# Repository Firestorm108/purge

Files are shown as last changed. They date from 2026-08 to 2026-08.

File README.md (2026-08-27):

# purge
**Purge** is a fully open source wireless inductively coupled plasma cleaner consisting of three isolated PCBs; the external user-control board, STM32 based motherboard, spark generator/ICP driver, and a vaccum chamber.

# PCB & Assembly
Screenshot 2026-08-26 at 1 35 50 PM
Screenshot 2026-08-26 at 3 20 42 PM

Screenshot 2026-08-26 at 2 14 10 PM
Screenshot 2026-08-26 at 3 26 43 PM

# The Process

**Purge** is a specialized type of plasma cleaner. There are **zero** electrodes in the vacuum chamber, meaning the sterility levels are very high, atomically sterile even. There are three stages to the process.

<h3>Stage 1: Chamber Prep</h3>
A 4.5 CFM standard vacuum pump evacuates much of the air inside of the glass dome to 37.5 mTorr. This makes the plasma much easier to form, as there is a reduced gas density. 
The chamber is made up of a custom machined aluminum base and a cheap glass dome you can find on Amazon. There is a slight implosion risk, so it is important you wear proper PPE.

<h3>Stage 2: Plasma Formation</h3>
There are two parts to the plasma formation. Since inductively coupled plasma (ICP) is relatively harder to form than capacitively coupled plasma or direct discharges, simply running the RF through the primary coil may not form the plasma.
To form the plasma, we initiate a short high voltage spark with an external device. In this case, I'm using a high frequency solid state plasma flame generator, similar to the ICP circuit itself. It ionizes some of the gas in the chamber, making
ICP form much easier. The ICP driver powers on after this, and the chamber fills with plasma.

<h3>Stage 3: Adjustment & Control</h3>
You can change the plasma inside the chamber using the built in STM32 interrupter. It allows you to pulse the plasma at any desired frequency within the chip and MOSFETs limits. This can be useful if you are trying to 
do research using the device, or wish to adjust power levels based on the item you are sterilizing.

# Bill of Materials

| Item | Price | Link |
|---|---:|---|
| Control PCB | $10 | JLCPCB |
| Header Pins | $3 | [AliExpress](https://www.aliexpress.us/item/3256801327743339.html) |
| OLED Screen | $4 | [AliExpress](https://www.aliexpress.us/item/3256805954920554.html) |
| 10K Potentiometers | $4 | [AliExpress](https://www.aliexpress.us/item/3256809938132755.html) |
| Push Button | $4 | [AliExpress](https://www.aliexpress.us/item/3256808590713102.html) |
| 3mm Flat Top LEDs | $2 | [AliExpress](https://www.aliexpress.us/item/2251801539552759.html) |
| F-F Jumpers | $2 | [AliExpress](https://www.aliexpress.us/item/2255800018543465.html) |
| ICP Driver PCB + Assembly | $55 | JLCPCB |
| FQA18N50 MOSFETs | $10 | [AliExpress](https://www.aliexpress.us/item/3256811881586105.html) |
| 6kV 33pF Capacitors | $2 | [AliExpress](https://www.aliexpress.us/item/2251832494176278.html) |
| 12AWG Solid Core | $4 | [AliExpress](https://www.aliexpress.us/item/3256808900976117.html) |
| Massive Heatsink | $10 | [AliExpress](https://www.aliexpress.us/item/3256809168389115.html) |
| HFSSTC Module | $24 | [AliExpress](https://www.aliexpress.us/item/3256810369157220.html) |
| 24AWG Solid Core (Inductor Wire) | $7 | [Amazon](https://www.amazon.com/0-2mm%C2%B2-Electrical-Colors-Tinned-breadboard/dp/B09WMQZYXV/) |
| 6AWG Primary Copper | $24 | [Amazon](https://www.amazon.com/99-9-Copper-Diameter-Jewelry-Making/dp/B0CNRT19WB/) |
| Purge Motherboard PCB + Assembly | $80 | JLCPCB |
| 24V → 12V Isolation SMPS | $6 | [AliExpress](https://www.aliexpress.us/item/3256807230654430.html) |
| 24V 10A Power Supply | $30 | [Amazon](https://www.amazon.com/Power-Supply-Adapter-Transformers-Universal/dp/B0D5B33JCH) |
| JLCPCB Customs & Shipping | $91 | JLCPCB |
| 4" × 7" Glass Dome | $30 | [Amazon](https://www.amazon.com/Plymor-Brand-Glass-Display-Cloche/dp/B006XIQGX8/) |
| 4.5 CFM Vacuum Pump | $60 | [Amazon](https://www.amazon.com/VECOTOOLS-Foldable-Automotive-Household-Maintenance/dp/B0GZVLP3PL/) |
| Hosing & Gauge | $28 | [Amazon](https://www.amazon.com/R410A-Recharge-Manifold-Gauge-Set/dp/B0DZ6G6ZBT/) |
| SAE to NPT Adapter | $9 | [Amazon](https://www.amazon.com/uxcell-Fitting-Connector-Conditioner-Refrigeration/dp/B08MZ4TPMZ/) |
| NPT Tap | $7 | [Amazon](https://www.amazon.com/Drill-America-DWTPT1-Qualtech-Carbon/dp/B01DZD1SSQ/) |
| M5 × 100mm Threaded Rods | $10 | [Amazon](https://www.amazon.com/LWCUSNJ-Threaded-M5-0-8mm-Stainless-Threads/dp/B0FHB8P689/) |
| Silicone Caulk | $3 | [Amazon](https://www.amazon.com/White-Acrylic-Latex-Caulk-Silicone/dp/B00GVLHBDG/) |
| Custom Aluminum Base Plate | $50 | JLC CNC |
| Silicone Isolation Feet | $20 | [Amazon](https://www.amazon.com/Isolation-Feet-8Pack-Turntable-Subwoofer-Resonance/dp/B0FX8S3D77) |

**Total: $589**

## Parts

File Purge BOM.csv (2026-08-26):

Item | Price | Link
Control PCB | $10 | JLCPCB
Header Pins | $3 | https://www.aliexpress.us/item/3256801327743339.html
OLED Screen | $4 | https://www.aliexpress.us/item/3256805954920554.html?
10K Potentiometers | $4 | https://www.aliexpress.us/item/3256809938132755.html
Push Button | $4 | https://www.aliexpress.us/item/3256808590713102.html?
3mm Flat Top LEDs | $2 | https://www.aliexpress.us/item/2251801539552759.html?
F-F Jumpers | $2 | https://www.aliexpress.us/item/2255800018543465.html
ICP Driver PCB + Assembly | $55 | JLCPCB
FQA18N50 MOSFETs | $10 | https://www.aliexpress.us/item/3256811881586105.html
6kV 33pF Capacitors | $2 | https://www.aliexpress.us/item/2251832494176278.html
12AWG Solid Core | $4 | https://www.aliexpress.us/item/3256808900976117.html
Massive Heatsink | $10 | https://www.aliexpress.us/item/3256809168389115.html
HFSSTC Module | $24 | https://www.aliexpress.us/item/3256810369157220.html?
24AWG Solid Core (Inductor Wire) | $7 | https://www.amazon.com/0-2mm%C2%B2-Electrical-Colors-Tinned-breadboard/dp/B09WMQZYXV/
6AWG Primary Copper | $24 | https://www.amazon.com/99-9-Copper-Diameter-Jewelry-Making/dp/B0CNRT19WB/
Purge Motherboard PCB + Assembly | $80 | JLCPCB
24V -> 12V Isolation SMPS | $6 | https://www.aliexpress.us/item/3256807230654430.html
24V 10A Power Supply | $30 | https://www.amazon.com/Power-Supply-Adapter-Transformers-Universal/dp/B0D5B33JCH
JLCPCB Customs & Shipping | $91 | :( JLCPCB
4"x7" Glass Dome | $30 | https://www.amazon.com/Plymor-Brand-Glass-Display-Cloche/dp/B006XIQGX8/ref=ast_sto_dp_puis?th=1
4.5CFM Vacuum Pump | $60 | https://www.amazon.com/VECOTOOLS-Foldable-Automotive-Household-Maintenance/dp/B0GZVLP3PL/
Hosing & Gauge | $28 | https://www.amazon.com/R410A-Recharge-Manifold-Gauge-Set/dp/B0DZ6G6ZBT/
SAE to NPT Adapter | $9 | https://www.amazon.com/uxcell-Fitting-Connector-Conditioner-Refrigeration/dp/B08MZ4TPMZ/
NPT Tap | $7 | https://www.amazon.com/Drill-America-DWTPT1-Qualtech-Carbon/dp/B01DZD1SSQ/
M5 x 100mm Threaded Rods | $10 | https://www.amazon.com/LWCUSNJ-Threaded-M5-0-8mm-Stainless-Threads/dp/B0FHB8P689/
Silicone Caulk | $3 | https://www.amazon.com/White-Acrylic-Latex-Caulk-Silicone/dp/B00GVLHBDG/
Custom Aluminum Base Plate | $50 | JLC CNC
Silicone Isolation Feet | $20 | https://www.amazon.com/Isolation-Feet-8Pack-Turntable-Subwoofer-Resonance/dp/B0FX8S3D77
Total: | $589

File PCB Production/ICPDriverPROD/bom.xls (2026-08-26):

Comment | Designator | Footprint | JLCPCB Part #
SIG | L1,J4,J1,J2,J5,L1,J4,J1,J2,J5,L1,J4,J1,J2,J5,L1,J4,J1,J2,J5,L1,J4,J1,J2,J5 | CONN-TH_P10.16_KF135T-10.16-2P | C475108
1K0.5W | R1,R2 | R_2512_6332Metric | C54315
1uF100V | C1 | C_1206_3216Metric | C13832
450V4.7nF | C2,C3 | C_1812_4532Metric | C692321
10K | R3,R4 | R_0603_1608Metric | C25804
IPT007N06N | U1,U2 | HSOF-8_IPT007N06N | C122552

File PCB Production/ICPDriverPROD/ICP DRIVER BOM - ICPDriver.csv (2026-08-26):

Id | Designator | Footprint | Quantity | Comment | Supplier and ref
1 | C1 | C_1206_3216Metric | 1 | 1uF 100V
2 | C2, C3 | C_1812_4532Metric | 2 | 450V 4.7nF
3 | C4, C5, C6, C7 | C_Disc_D7.5mm_W5.0mm_P7.50mm | 4 | 6kV 33pF
4 | J1 | CONN-TH_P10.16_KF135T-10.16-2P | 1 | ICP Primary
5 | J2 | CONN-TH_P10.16_KF135T-10.16-2P | 1 | Plasma Flame
6 | J4 | CONN-TH_P10.16_KF135T-10.16-2P | 1 | VIN
7 | J5 | CONN-TH_P10.16_KF135T-10.16-2P | 1 | SIG
8 | L1 | CONN-TH_P10.16_KF135T-10.16-2P | 1 | 10uH
9 | Q1 | TO-247-3_Vertical | 1 | FDA18N50
10 | R1, R2 | R_2512_6332Metric | 2 | 1K 0.5W
11 | R3, R4 | R_0603_1608Metric | 2 | 10K
12 | RV1 | RES-ADJ-TH_RK1631110U1Q | 1 | 10K
13 | U1, U2 | HSOF-8_IPT007N06N | 2 | IPT007N06N

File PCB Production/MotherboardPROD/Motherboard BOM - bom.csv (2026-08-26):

Id | Designator | Footprint | Quantity | Comment | Supplier and ref
1 | C10, C17, C33, C36, C37, C44, C45 | C_0603_1608Metric | 7 | 10uF
2 | C11, C14, C15, C30, C31, C39 | C_0603_1608Metric | 6 | 1uF
3 | C12, C13 | C_0603_1608Metric | 2 | 2.2uF
4 | C16, C18, C19, C24, C25, C26, C27, C28, C29, C38, C43 | C_0402_1005Metric | 11 | 100nF
5 | C20, C21 | C_0402_1005Metric | 2 | 10pF
6 | C22, C23 | C_0402_1005Metric | 2 | 30pF
7 | D1, D3 | D_SOD-323 | 2 | 1N5819WS
8 | D5, D6, D7, D8 | LED_0805_2012Metric | 4 | LED
9 | J1 | CONN-TH_P10.16_KF135T-10.16-2P | 1 | 12VDC
10 | J3 | USB_C_Receptacle_HRO_TYPE-C-31-M-12 | 1 | USB_C_Receptacle_USB2.0_14P
11 | J4 | PinHeader_1x12_P2.54mm_Vertical | 1 | Conn_01x12
12 | J9 | CONN-TH_P10.16_KF135T-10.16-2P | 1 | Driver Signals
13 | R3, R6, R7, R9, R10, R11, R12, R18, R22, R23, R24, R25 | R_0603_1608Metric | 12 | 10K
14 | R4, R5 | R_0603_1608Metric | 2 | 5.1K
15 | R13, R14, R15, R20 | R_0603_1608Metric | 4 | 4.7K
16 | R17, R19 | R_0603_1608Metric | 2 | 330
17 | SW1, SW2 | SW_Push_SPST_NO_Alps_SKRK | 2 | SW_Push
18 | U1 | LQFP-64_10x10mm_P0.5mm | 1 | STM32H573RIT6
19 | U3 | TO-263-2_L10.0-W9.2-P5.08-LS15.3-TL-CW | 1 | L7805ABD2T-TR
20 | U4 | SOT-23-6 | 1 | USBLC6-2SC6
21 | U5 | SOT-223-3_TabPin2 | 1 | LD1117S33TR_SOT223
22 | U6, U11 | SOIC-8_L5.0-W4.0-P1.27-LS6.0-BL | 2 | TC4420EOA713
23 | U8, U10 | OPTO-SMD-5_L3.7-W4.6-P1.27-LS7.0-BR | 2 | TLP2362
24 | X1 | CRYSTAL-SMD_L3.2-W1.5-1 | 1 | FC-135 32.7680KA-AG3
25 | X2 | OSC-SMD_L5.0-W3.2 | 1 | ABM3-8.000MHZ-D2Y-T

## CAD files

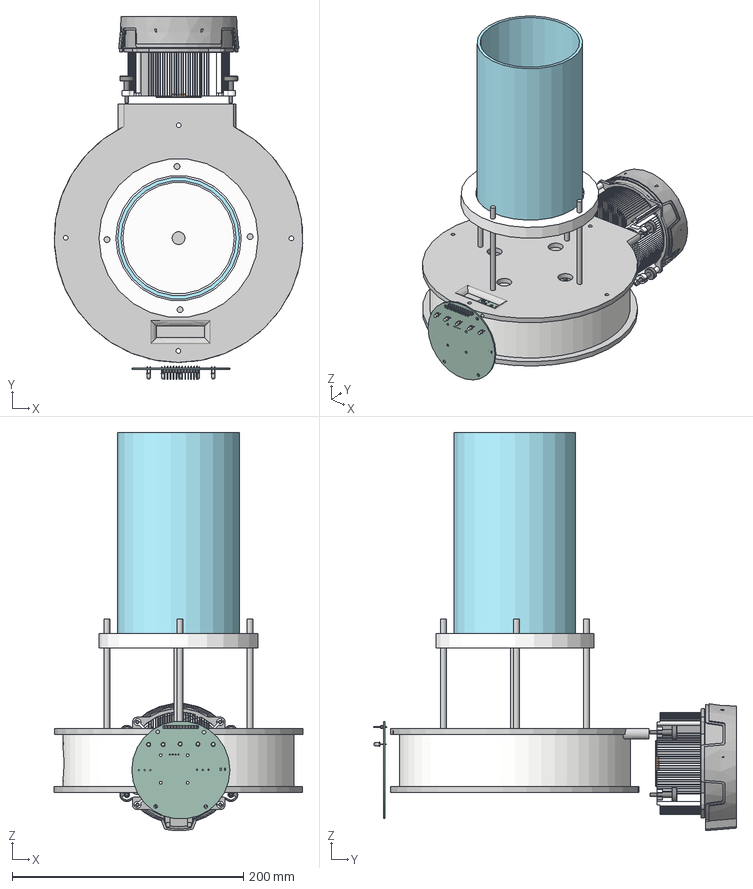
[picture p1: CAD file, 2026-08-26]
CAD/Assembly.step
214.9 x 313.9 x 344.5 mm

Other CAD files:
CAD/Assembly.f3z
CAD_/Assembly.f3z

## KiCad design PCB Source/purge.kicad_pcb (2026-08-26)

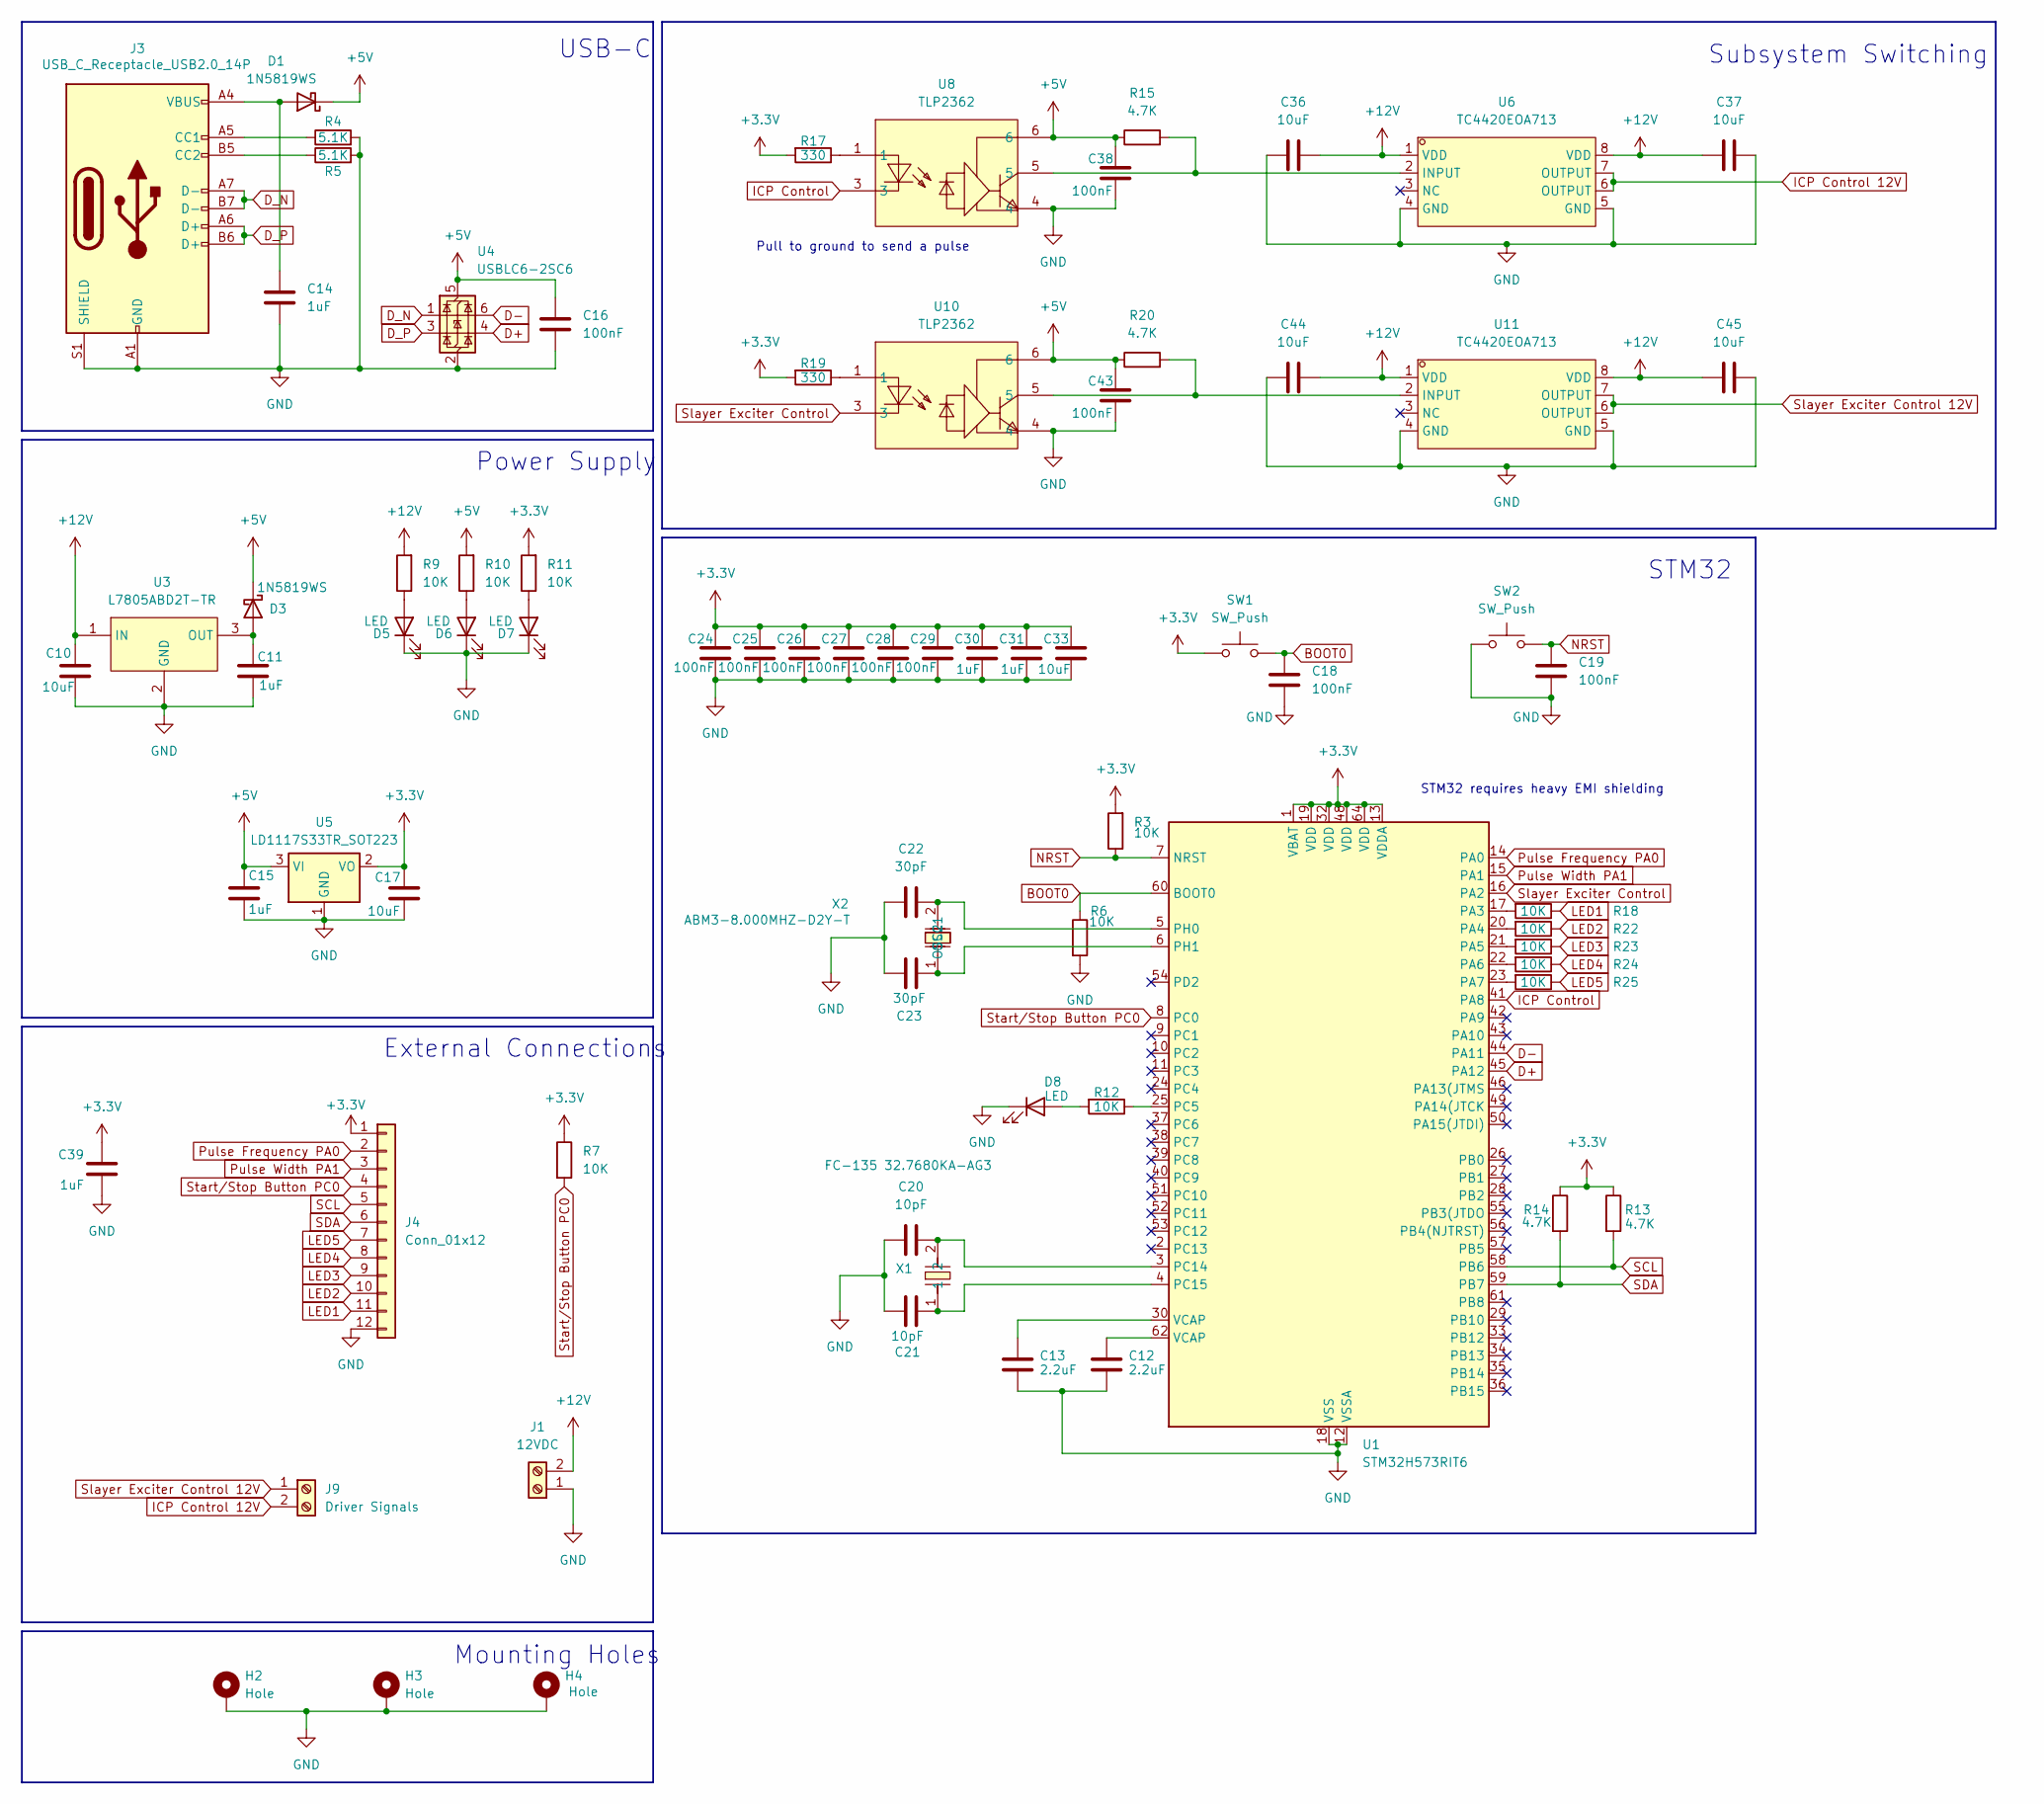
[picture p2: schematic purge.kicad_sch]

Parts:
C10, C17, C33, C36, C37, C44, C45: 10uF; C_0603_1608Metric
C11, C14, C15, C30, C31, C39: 1uF; C_0603_1608Metric
C12, C13: 2.2uF; C_0603_1608Metric
C16, C18, C19, C24, C25, C26, C27, C28, C29, C38, C43: 100nF; C_0402_1005Metric
C20, C21: 10pF; C_0402_1005Metric
C22, C23: 30pF; C_0402_1005Metric
D1, D3: 1N5819WS; D_SOD-323
D5, D6, D7, D8: LED; LED_0805_2012Metric
H2, H3, H4: Hole; MountingHole_3.2mm_M3_Pad
J1: 12VDC; CONN-TH_P10.16_KF135T-10.16-2P
J3: USB_C_Receptacle_USB2.0_14P; USB_C_Receptacle_HRO_TYPE-C-31-M-12
J4: Conn_01x12; PinHeader_1x12_P2.54mm_Vertical
J9: Driver Signals; CONN-TH_P10.16_KF135T-10.16-2P
R3, R6, R7, R9, R10, R11, R12, R18, R22, R23, R24, R25: 10K; R_0603_1608Metric
R4, R5: 5.1K; R_0603_1608Metric
R13, R14, R15, R20: 4.7K; R_0603_1608Metric
R17, R19: 330; R_0603_1608Metric
SW1, SW2: SW_Push; SW_Push_SPST_NO_Alps_SKRK
U1: STM32H573RIT6; LQFP-64_10x10mm_P0.5mm
U3: L7805ABD2T-TR; TO-263-2_L10.0-W9.2-P5.08-LS15.3-TL-CW; MPN L7805ABD2T-TR; LCSC Part C86206
U4: USBLC6-2SC6; SOT-23-6
U5: LD1117S33TR_SOT223; SOT-223-3_TabPin2
U6, U11: TC4420EOA713; SOIC-8_L5.0-W4.0-P1.27-LS6.0-BL; MPN TC4420EOA713; LCSC Part C231865
U8, U10: TLP2362; OPTO-SMD-5_L3.7-W4.6-P1.27-LS7.0-BR; MPN TLP2362(TPL,E; LCSC Part C37658
X1: FC-135 32.7680KA-AG3; CRYSTAL-SMD_L3.2-W1.5-1; MPN FC-135 32.7680KA-AG3; LCSC Part C7275970
X2: ABM3-8.000MHZ-D2Y-T; OSC-SMD_L5.0-W3.2; MPN ABM3-8.000MHZ-D2Y-T; LCSC Part C144380

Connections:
+3.3V: C17.1, C24.1, C25.1, C26.1, C27.1, C28.1, C29.1, C30.1, C31.1, C33.1, C39.1, J4.1, R3.2, R7.1, R11.2, R13.1, R14.1, R17.2, R19.2, SW1.1, U1.1 (VBAT), U1.13 (VDDA), U1.19 (VDD), U1.32 (VDD), U1.48 (VDD), U1.64 (VDD), U5.2 (VO)
+5V: C15.1, C16.1, C38.1, C43.1, D1.1 (K), D3.1 (K), R10.2, R15.1, R20.1, U4.5 (VBUS), U5.3 (VI), U8.6, U10.6
+12V: C10.1, C36.2, C37.1, C44.2, C45.1, J1.2, R9.2, U3.1 (IN), U6.1 (VDD), U6.8 (VDD), U11.1 (VDD), U11.8 (VDD)
BOOT0: C18.1, R6.1, SW1.2, U1.60 (BOOT0)
D+: U1.45 (PA12), U4.4 (I/O2)
D-: U1.44 (PA11), U4.6 (I/O1)
D_N: J3.A7 (D-), J3.B7 (D-), U4.1 (I/O1)
D_P: J3.A6 (D+), J3.B6 (D+), U4.3 (I/O2)
GND: C10.2, C11.2, C12.2, C13.2, C14.2, C15.2, C16.2, C17.2, C18.2, C19.2, C20.1, C21.1, C22.1, C23.1, C24.2, C25.2, C26.2, C27.2, C28.2, C29.2, C30.2, C31.2, C33.2, C36.1, C37.2, C38.2, C39.2, C43.2, C44.1, C45.2, D5.1 (K), D6.1 (K), D7.1 (K), D8.1 (K), H2.1 (1_1), H3.1 (1_1), H4.1 (1_1), J1.1, J3.A1 (GND), J3.A12 (GND), J3.B1 (GND), J3.B12 (GND), J3.S1 (SHIELD), J4.12, R4.2, R5.2, R6.2, SW2.1, U1.12 (VSSA), U1.18 (VSS), U1.31 (VSS), U1.47 (VSS), U1.63 (VSS), U3.2 (GND), U4.2 (GND), U5.1 (GND), U6.4 (GND), U6.5 (GND), U8.4, U10.4, U11.4 (GND), U11.5 (GND)
ICP Control: U1.41 (PA8), U8.3
ICP Control 12V: J9.2, U6.6 (OUTPUT), U6.7 (OUTPUT)
LED1: J4.11, R18.1
LED2: J4.10, R22.1
LED3: J4.9, R23.1
LED4: J4.8, R24.1
LED5: J4.7, R25.1
NRST: C19.1, R3.1, SW2.2, U1.7 (NRST)
unnamed: C12.1, U1.62 (VCAP)
unnamed: C13.1, U1.30 (VCAP)
unnamed: C14.1, D1.2 (A), J3.A4 (VBUS), J3.A9 (VBUS), J3.B4 (VBUS), J3.B9 (VBUS)
unnamed: C11.1, D3.2 (A), U3.3 (OUT)
unnamed: D5.2 (A), R9.1
unnamed: D6.2 (A), R10.1
unnamed: D7.2 (A), R11.1
unnamed: D8.2 (A), R12.2
unnamed: J3.A5 (CC1), R4.1
unnamed: J3.B5 (CC2), R5.1
unnamed: R17.1, U8.1
unnamed: R19.1, U10.1
unnamed: R18.2, U1.17 (PA3)
unnamed: R22.2, U1.20 (PA4)
unnamed: R23.2, U1.21 (PA5)
unnamed: R24.2, U1.22 (PA6)
unnamed: R25.2, U1.23 (PA7)
unnamed: R12.1, U1.25 (PC5)
unnamed: C20.2, U1.3 (PC14), X1.2
unnamed: C21.2, U1.4 (PC15), X1.1
unnamed: C22.2, U1.5 (PH0), X2.2 (OSC2)
unnamed: C23.2, U1.6 (PH1), X2.1 (OSC1)
unnamed: R15.2, U6.2 (INPUT), U8.5
unnamed: R20.2, U10.5, U11.2 (INPUT)
Pulse Frequency PA0: J4.2, U1.14 (PA0)
Pulse Width PA1: J4.3, U1.15 (PA1)
SCL: J4.5, R13.2, U1.58 (PB6)
SDA: J4.6, R14.2, U1.59 (PB7)
Slayer Exciter Control: U1.16 (PA2), U10.3
Slayer Exciter Control 12V: J9.1, U11.6 (OUTPUT), U11.7 (OUTPUT)
Start/Stop Button PC0: J4.4, R7.2, U1.8 (PC0)

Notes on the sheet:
USB-C
External Connections
Subsystem Switching
Mounting Holes
Power Supply
STM32 requires heavy EMI shielding
STM32
Pull to ground to send a pulse

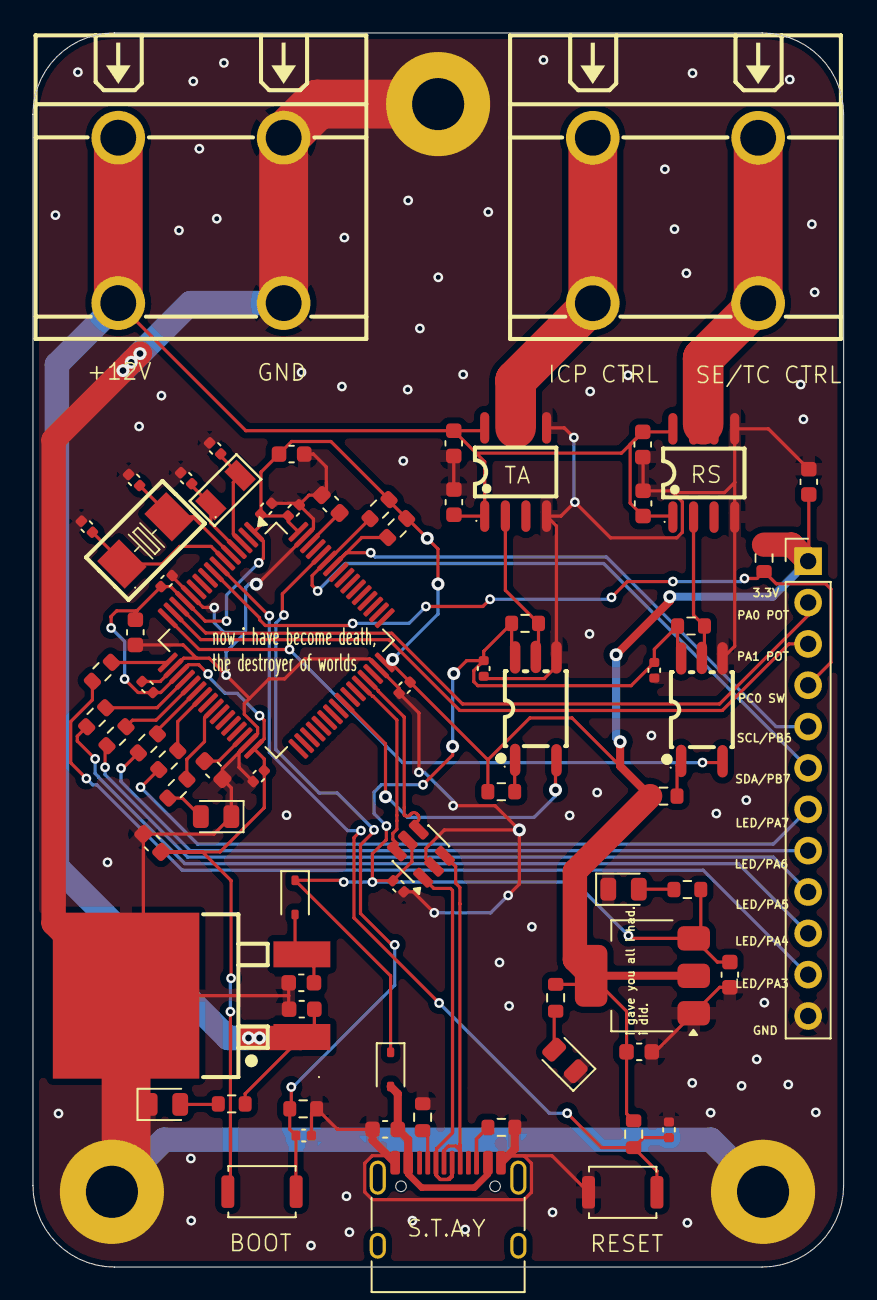
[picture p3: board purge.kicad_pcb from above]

Board: 2 copper layers, 49.8 x 75.8 mm, 75 parts (0 on the bottom side), 48 nets.

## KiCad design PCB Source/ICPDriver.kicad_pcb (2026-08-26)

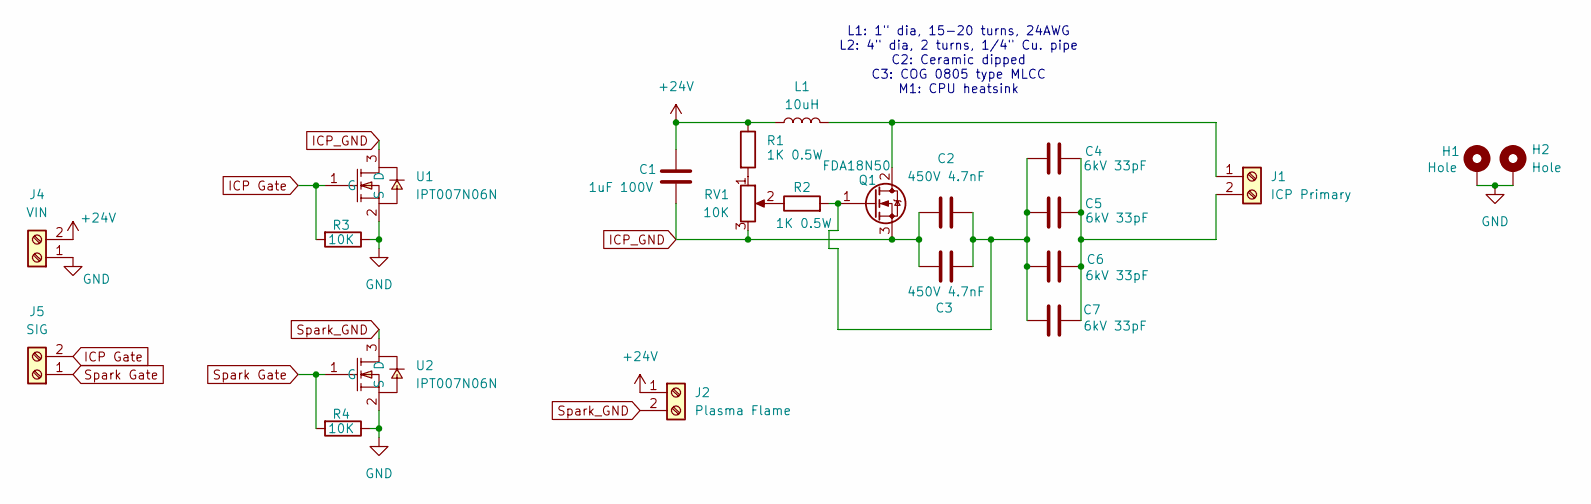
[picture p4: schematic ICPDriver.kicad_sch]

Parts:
C1: 1uF 100V; C_1206_3216Metric
C2, C3: 450V 4.7nF; C_1812_4532Metric
C4, C5, C6, C7: 6kV 33pF; C_Disc_D7.5mm_W5.0mm_P7.50mm
H1, H2: Hole; MountingHole_3.2mm_M3_Pad
J1: ICP Primary; CONN-TH_P10.16_KF135T-10.16-2P
J2: Plasma Flame; CONN-TH_P10.16_KF135T-10.16-2P
J4: VIN; CONN-TH_P10.16_KF135T-10.16-2P
J5: SIG; CONN-TH_P10.16_KF135T-10.16-2P
L1: 10uH; CONN-TH_P10.16_KF135T-10.16-2P
Q1: FDA18N50; TO-247-3_Vertical
R1, R2: 1K 0.5W; R_2512_6332Metric
R3, R4: 10K; R_0603_1608Metric
RV1: 10K; RES-ADJ-TH_RK1631110U1Q
U1, U2: IPT007N06N; HSOF-8_IPT007N06N; MPN IPT007N06N(TOKMAS); LCSC Part C19626228

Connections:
+24V: C1.1, J2.1, J4.2, L1.1, R1.1
GND: H1.1 (1_1), H2.1 (1_1), J4.1, R3.1, R4.1, U1.2 (S), U2.2 (S)
ICP Gate: J5.2, R3.2, U1.1 (G)
ICP_GND: C1.2, C2.1, C3.1, Q1.3 (S), RV1.3, U1.3 (D)
unnamed: J1.1, L1.2, Q1.2 (D)
unnamed: C4.2, C5.2, C6.2, C7.2, J1.2
unnamed: C2.2, C3.2, C4.1, C5.1, C6.1, C7.1, Q1.1 (G), R2.2
unnamed: R1.2, RV1.1
unnamed: R2.1, RV1.2
Spark Gate: J5.1, R4.2, U2.1 (G)
Spark_GND: J2.2, U2.3 (D)

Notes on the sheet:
L1: 1" dia, 15-20 turns, 24AWG L2: 4" dia, 2 turns, 1/4" Cu. pipe C2: Ceramic dipped C3: COG 0805 type MLCC M1: CPU heatsink

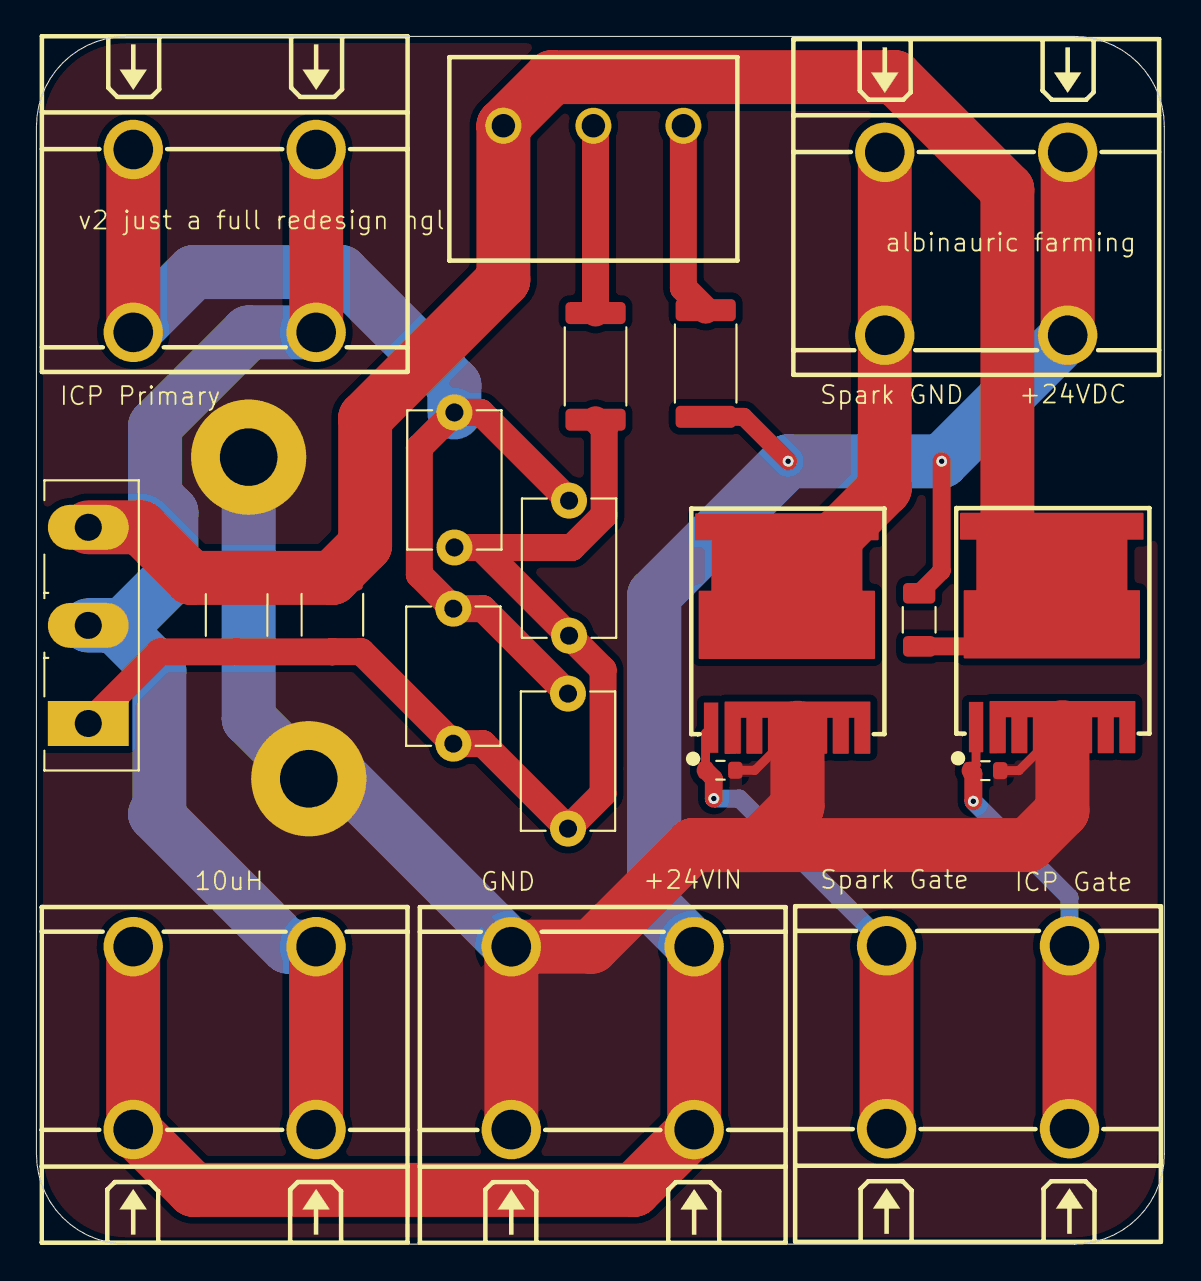
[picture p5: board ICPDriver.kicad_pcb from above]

Board: 2 copper layers, 62.7 x 67.1 mm, 22 parts (0 on the bottom side), 11 nets.

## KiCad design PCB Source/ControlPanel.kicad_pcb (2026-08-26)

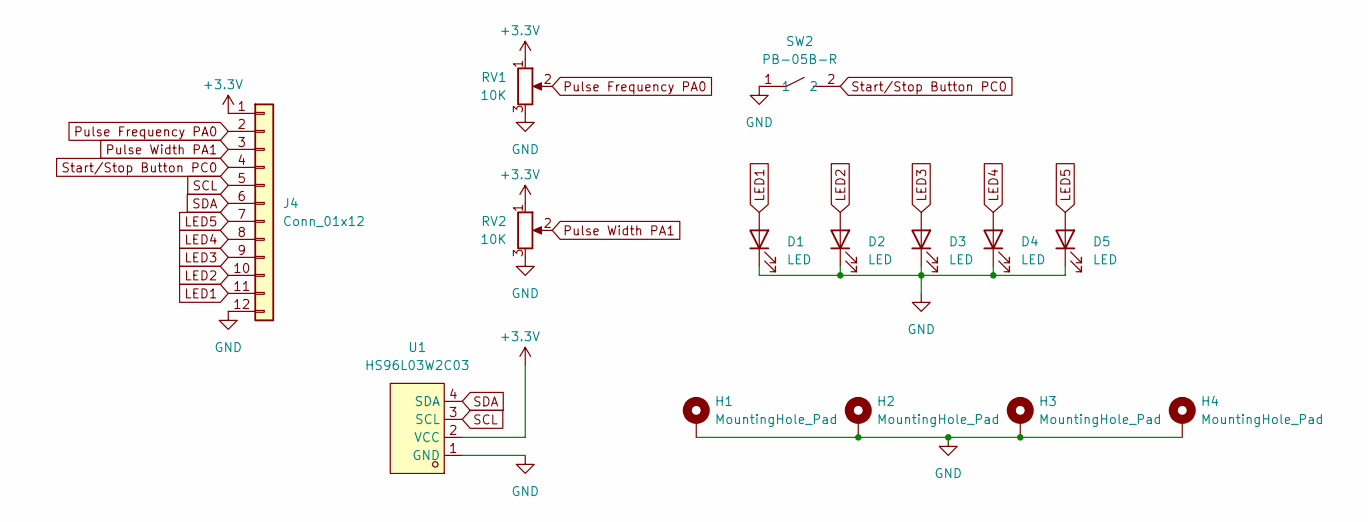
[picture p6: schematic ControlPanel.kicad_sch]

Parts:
D1, D2, D3, D4, D5: LED; LED_D3.0mm
H1, H2, H3, H4: MountingHole_Pad; MountingHole_3.2mm_M3_Pad
J4: Conn_01x12; PinHeader_1x12_P2.54mm_Vertical
RV1, RV2: 10K; Potentiometer_Alps_RK163_Single_Horizontal
SW2: PB-05B-R; CONN-TH_PB-05B-R; MPN PB-05B-R; LCSC Part C268254
U1: HS96L03W2C03; OLED-TH_L27.8-W27.2-P2.54_C9900033791; MPN HS96L03W2C03; LCSC Part C5248080

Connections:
+3.3V: J4.1, RV1.1, RV2.1, U1.2 (VCC)
GND: D1.1 (K), D2.1 (K), D3.1 (K), D4.1 (K), D5.1 (K), H1.1 (1_1), H2.1 (1_1), H3.1 (1_1), H4.1 (1_1), J4.12, RV1.3, RV2.3, SW2.1, U1.1 (GND)
LED1: D1.2 (A), J4.11
LED2: D2.2 (A), J4.10
LED3: D3.2 (A), J4.9
LED4: D4.2 (A), J4.8
LED5: D5.2 (A), J4.7
Pulse Frequency PA0: J4.2, RV1.2
Pulse Width PA1: J4.3, RV2.2
SCL: J4.5, U1.3 (SCL)
SDA: J4.6, U1.4 (SDA)
Start/Stop Button PC0: J4.4, SW2.2

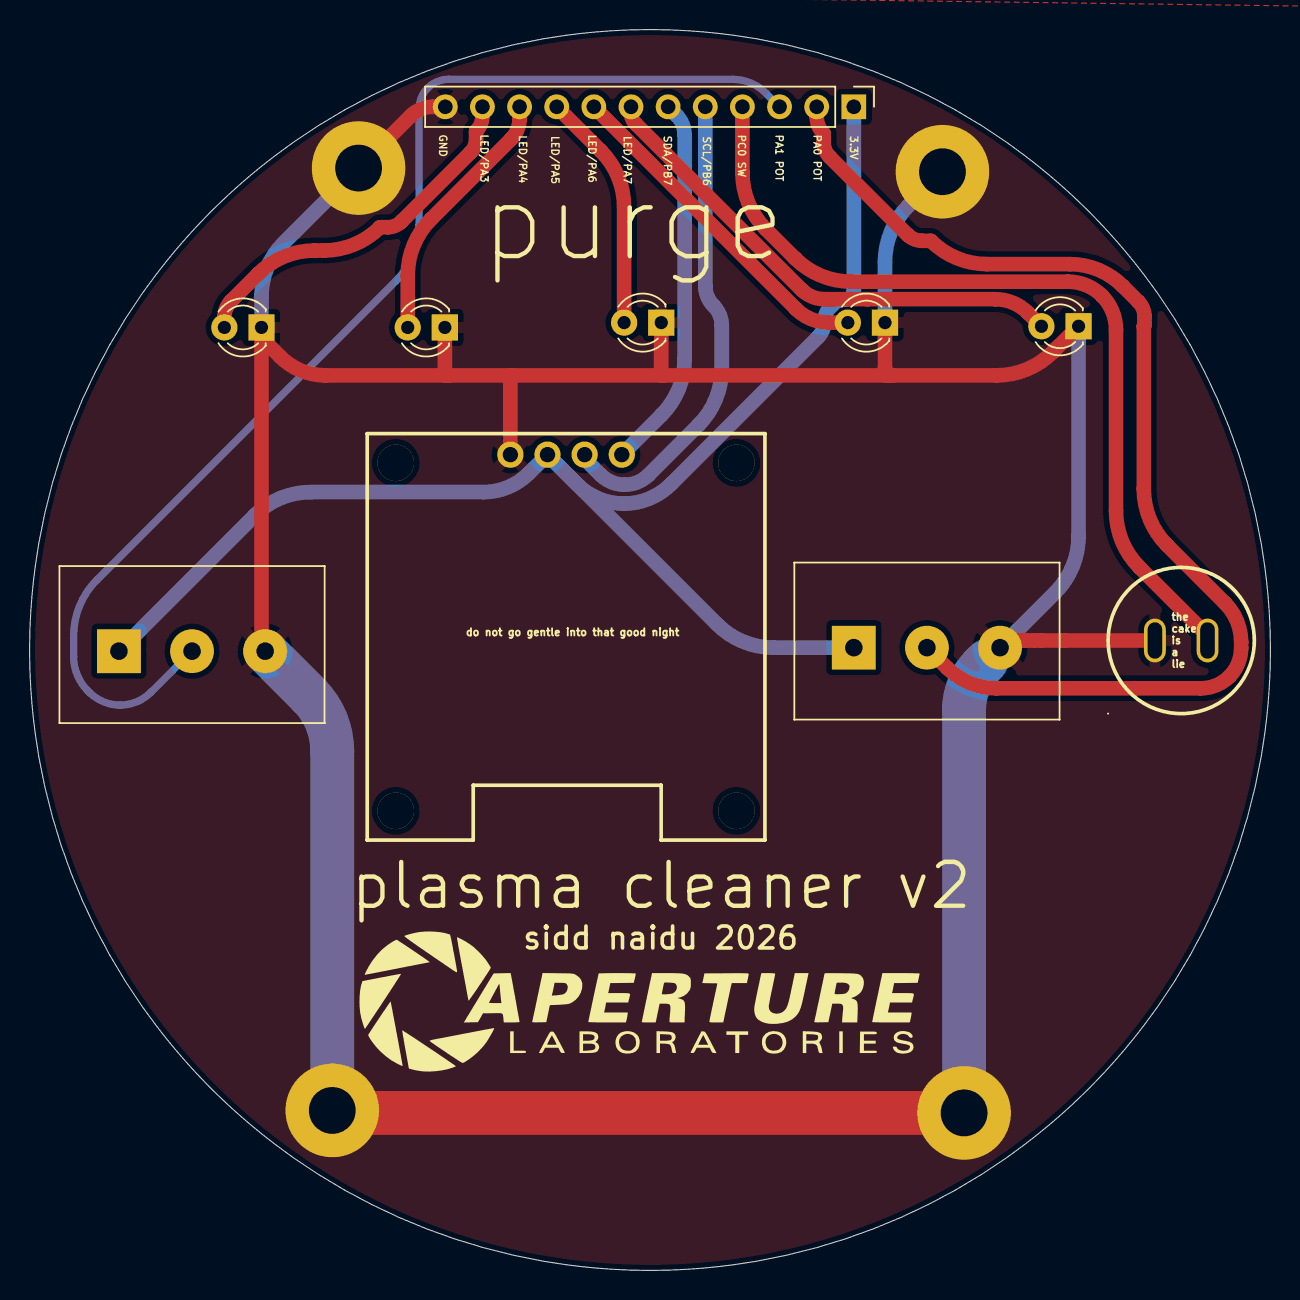
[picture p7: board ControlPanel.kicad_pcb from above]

Board: 2 copper layers, 84.9 x 84.9 mm, 14 parts (0 on the bottom side), 12 nets.

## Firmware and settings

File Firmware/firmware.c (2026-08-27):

/* USER CODE BEGIN Includes */
#include "ssd1306.h"   // Include your OLED library
#include <stdio.h>     // Needed for sprintf
/* USER CODE END Includes */

/* USER CODE BEGIN PV */
uint16_t pot1_value = 0;
uint16_t pot2_value = 0;
volatile uint8_t button_pressed_flag = 0; // 'volatile' is crucial for interrupt variables
/* USER CODE END PV */

/* USER CODE BEGIN 0 */
// This function is automatically called by the HAL when the button is pressed
void HAL_GPIO_EXTI_Callback(uint16_t GPIO_Pin) {
    if(GPIO_Pin == GPIO_PIN_13) { // Replace PIN_13 with your actual button pin
        button_pressed_flag = 1; 
    }
}
/* USER CODE END 0 */

int main(void)
{
  // ... System setup and initialization code generated by CubeMX ...

  /* USER CODE BEGIN 2 */
  // Initialize the OLED screen
  ssd1306_Init();
  ssd1306_Fill(Black);
  ssd1306_SetCursor(2, 0);
  ssd1306_WriteString("STM32 Ready!", Font_7x10, White);
  ssd1306_UpdateScreen();
  /* USER CODE END 2 */

  /* Infinite loop */
  /* USER CODE BEGIN WHILE */
  while (1)
  {
    // 1. Read Potentiometer 1
    HAL_ADC_Start(&hadc1);
    HAL_ADC_PollForConversion(&hadc1, 10);
    pot1_value = HAL_ADC_GetValue(&hadc1);

    // 2. Read Potentiometer 2
    HAL_ADC_Start(&hadc1); 
    HAL_ADC_PollForConversion(&hadc1, 10);
    pot2_value = HAL_ADC_GetValue(&hadc1);
    HAL_ADC_Stop(&hadc1);

    // 3. Update the OLED Screen
    char buffer[32];
    ssd1306_Fill(Black); // Clear screen for new data
    
    // Format and print Pot 1
    sprintf(buffer, "Pot 1: %u", pot1_value);
    ssd1306_SetCursor(2, 0);
    ssd1306_WriteString(buffer, Font_7x10, White);

    // Format and print Pot 2
    sprintf(buffer, "Pot 2: %u", pot2_value);
    ssd1306_SetCursor(2, 15);
    ssd1306_WriteString(buffer, Font_7x10, White);

    // 4. Handle the Button Interrupt
    if (button_pressed_flag) {
        ssd1306_SetCursor(2, 30);
        ssd1306_WriteString("INTERRUPT!", Font_7x10, White);
        
        // Reset the flag so it only triggers once per press
        button_pressed_flag = 0; 
    }

    ssd1306_UpdateScreen();
    HAL_Delay(100); // A small delay stops the screen from flickering
    /* USER CODE END WHILE */
  }
}

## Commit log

2026-08-26 Rename Purge BOM - Sheet1.csv to Purge BOM.csv
    [Purge BOM.csv]
2026-08-26 Rename Purge BOM - Sheet1 (1).csv to Purge BOM.csv
    [Purge BOM.csv]
2026-08-30 Rename folders
    [Assembly.f3z, Assembly.step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]
